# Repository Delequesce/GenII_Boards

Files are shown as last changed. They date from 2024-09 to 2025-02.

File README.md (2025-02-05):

## Rev 3 Changes

### Pi Interface and Power Board
1) ~~Set 4 LSBs of each color going into the RGB interface HIGH. This still allows for 4096 possible colors but frees up 12 total GPIOs.~~
2) ~~Replaced source switching circuitry with a source selector IC (LTC4412)~~. ~~Also implemented circuitry to enable the STM32 to shutdown and wakeup the Pi with the power button for better power management.~~ 
3) ~~Replaced the Pi Zero W with a Pi Zero 2 W.~~
4) ~~Added I2C RESET pin for enabling the capacitive touch screen~~
5) ~~Moved the FPC connector to the Measurement Board to the top of the board to ease assembly.~~ 
6) ~~Moved the RGB and I2C connectors to the screen closer to the edge (or top with flipped connections) to ease assembly.~~ 
7) ~~Fixed wiring issues for Vdd and Vcc out to the Measurement Board.~~
8) ~~Increased the size of the mounting holes for the battery cables to ease connection. (0.65 mm diameter for 22 AWG)~~
9) ~~Generally improved power routing~~
10) ~~Improved PWM backlight enable routing for better fidelity.~~
11) ~~Specced out smaller battery connectors to ease assembly and reduce size. (22 AWG, Amazon)~~
12) ~~Moved the Vdd Main LDO to the Measurement Board~~
13) ~~Added a fuse to the TPS2400 circuit and also a fuse after the source selector.~~
14) ~~Added a small board meant to be separated for interfacing the pushbutton reset switch with the rest of the circuit.~~

### Measurement Board
1) ~~Fixed PWM Heater signal routing~~ 
2) ~~Flipped FPC connector to Pi Board to top of board to ease assembly. Checked wiring against the Pi board.~~
3) ~~Moved Vdd Main LDO from Pi Board.~~ 
4) ~~Added external interrupt pin and Vcc controller output pin to interface with external pushbutton board. Needed to add 50 mils (1.27 mm) to board length.~~
5) ~~Changed the ADR4530 to the MAX6070, a cheaper buffered reference requiring fewer parts.~~

### Heater Board
1) ~~Reduced the size of vias and made more of them for better heating and lower losses. ~~
2) Moved the thermistors slightly farther from the center to improve temperature tracking. Alternately just reduced the size of the heating area to improve tracking without separating the thermistors from the chip. (Maybe)

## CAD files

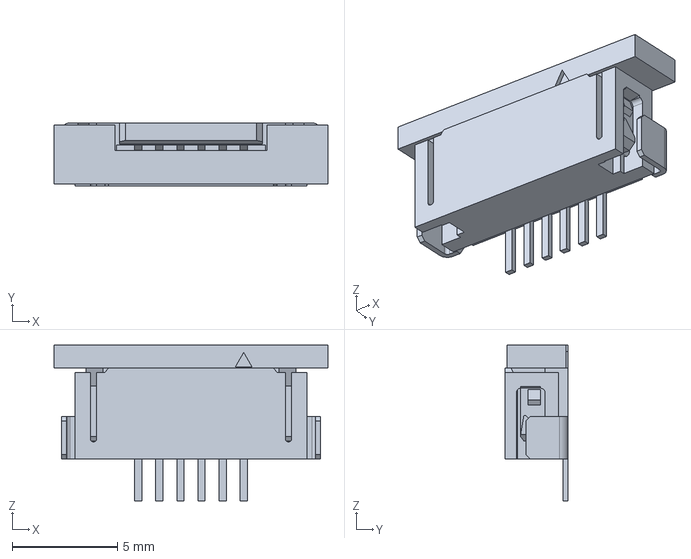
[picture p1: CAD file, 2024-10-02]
Raspi_Zero_TFT_Interface/Molex_0522710679/52271-0679.step
13.0 x 3.00 x 7.40 mm

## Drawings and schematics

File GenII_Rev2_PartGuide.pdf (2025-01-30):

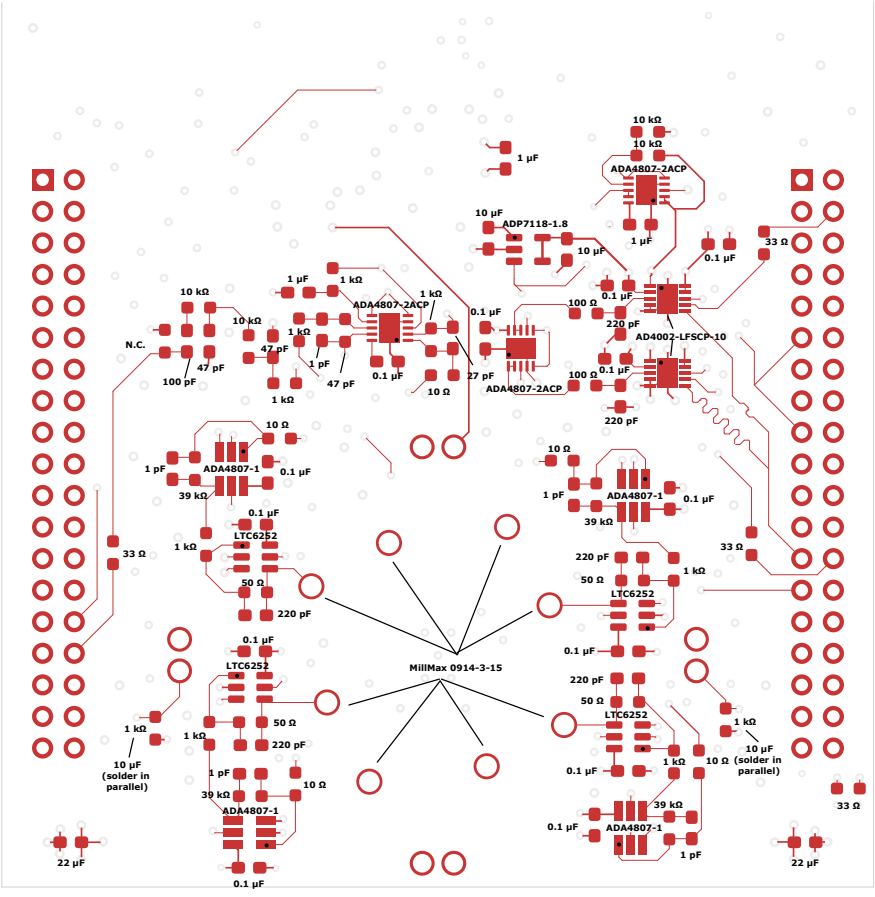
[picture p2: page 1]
10 μF (solder in parallel); ADA4807-2ACP; AD4002-LFSCP-10; ADA4807-1; LTC6252; MillMax 0914-3-15; ADP7118-1.8

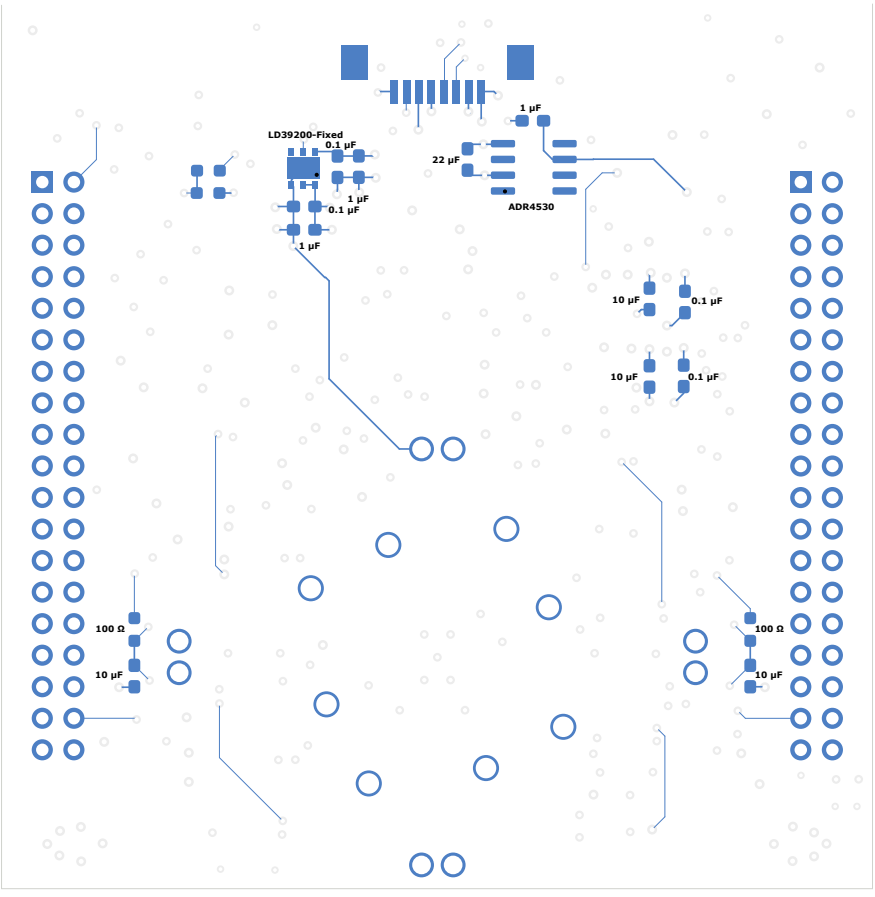
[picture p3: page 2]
LD39200-Fixed 0.1 μF; ADR4530

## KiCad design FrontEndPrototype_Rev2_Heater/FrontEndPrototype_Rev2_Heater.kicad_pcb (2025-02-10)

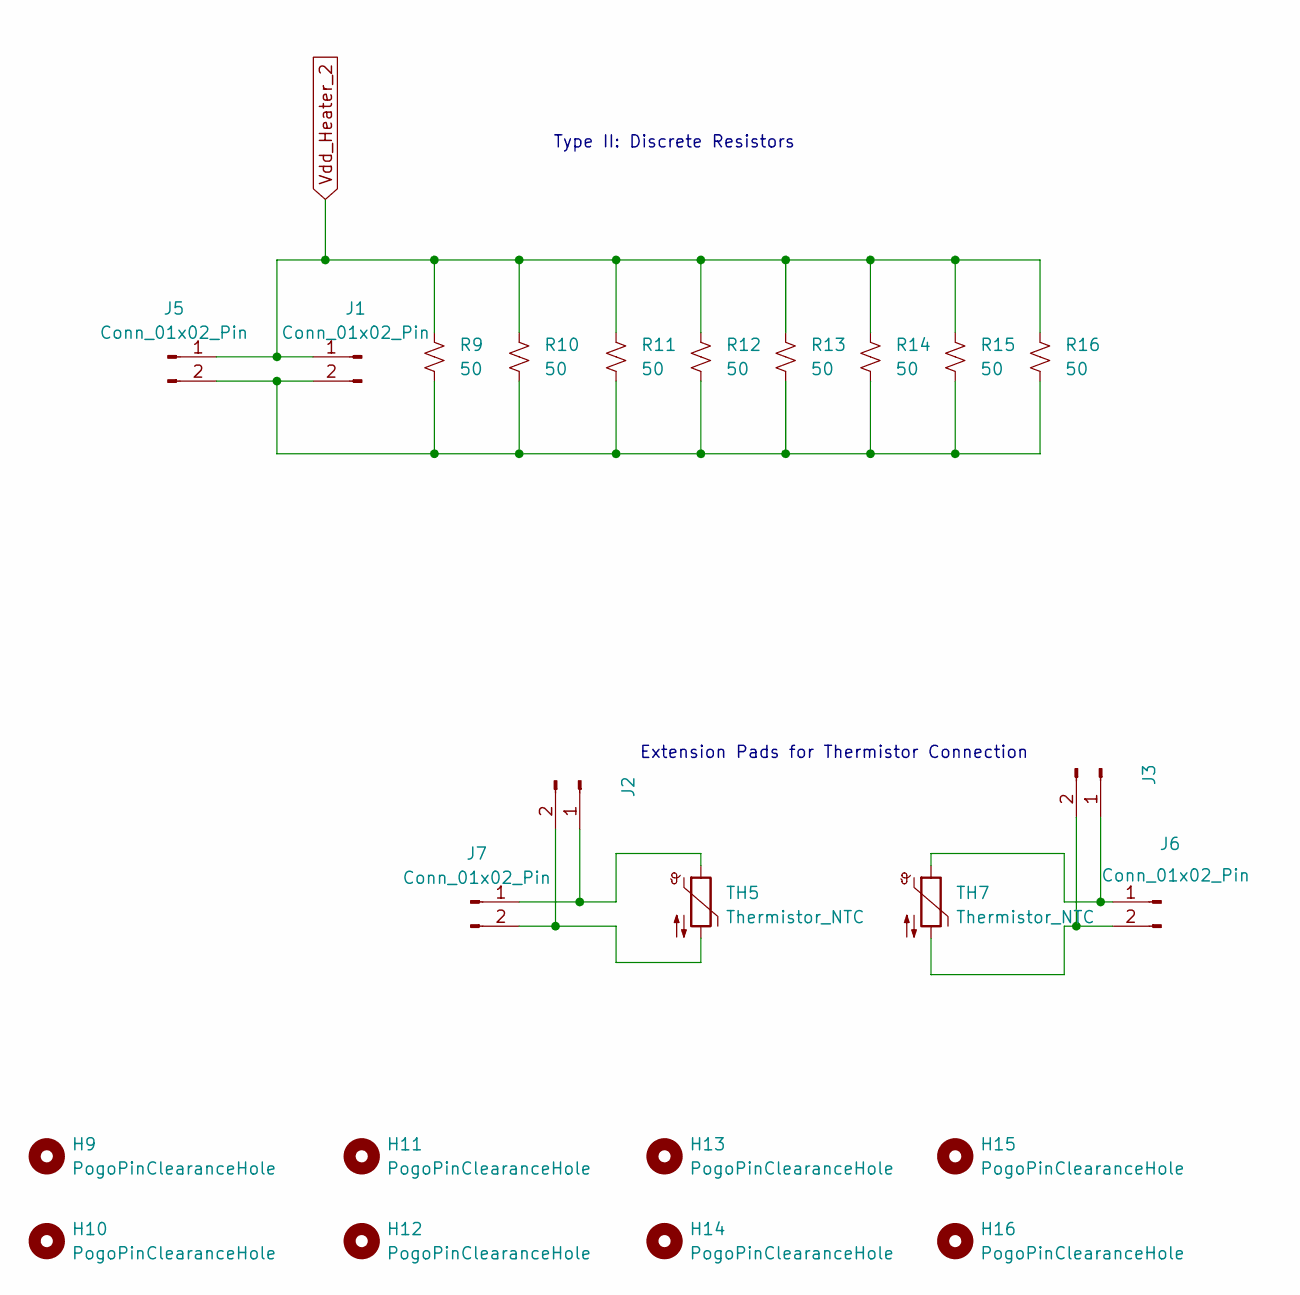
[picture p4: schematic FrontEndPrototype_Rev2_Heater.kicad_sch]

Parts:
H9, H10, H11, H12, H13, H14, H15, H16: PogoPinClearanceHole; PogoClearanceHole
J1, J5, J6, J7: Conn_01x02_Pin; Samtec_Pin_Socket_SS_102_G_2
J2, J3: Conn_01x02_Pin; Thermistor_ExtensionPad
R9, R10, R11, R12, R13, R14, R15, R16: 50; R_2010_5025Metric_Pad1.40x2.65mm_HandSolder
TH5, TH7: Thermistor_NTC; R_0603_1608Metric_Pad0.98x0.95mm_HandSolder

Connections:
unnamed: J1.2, J5.2, R9.1, R10.1, R11.1, R12.1, R13.1, R14.1, R15.1, R16.1
unnamed: J2.1, J7.1, TH5.1
unnamed: J2.2, J7.2, TH5.2
unnamed: J3.1, J6.1, TH7.1
unnamed: J3.2, J6.2, TH7.2
Vdd_Heater_2: J1.1, J5.1, R9.2, R10.2, R11.2, R12.2, R13.2, R14.2, R15.2, R16.2

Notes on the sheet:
Extension Pads for Thermistor Connection
Type II: Discrete Resistors

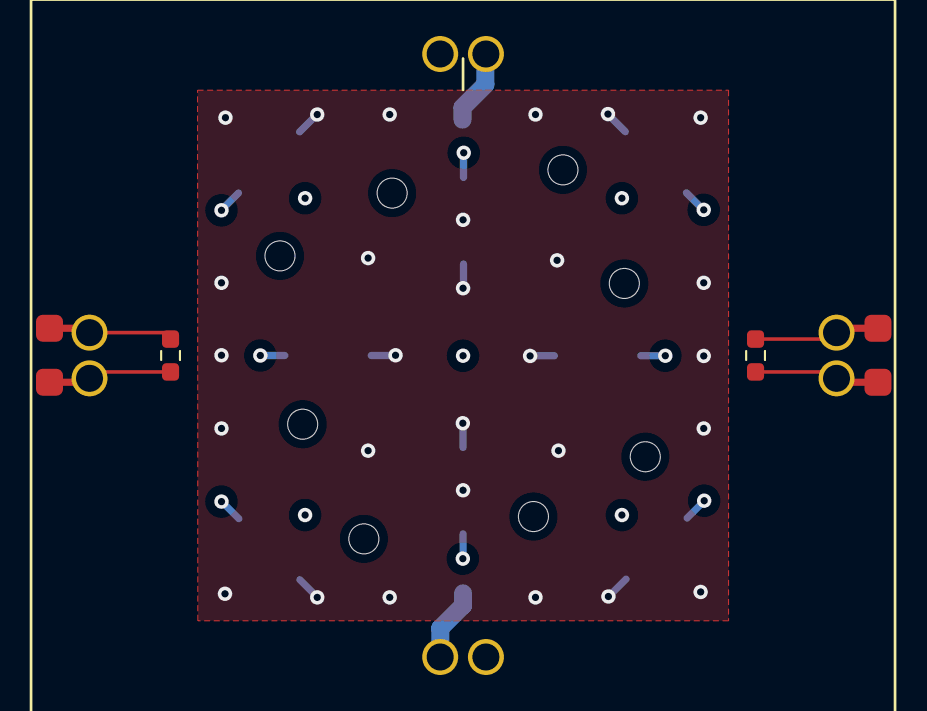
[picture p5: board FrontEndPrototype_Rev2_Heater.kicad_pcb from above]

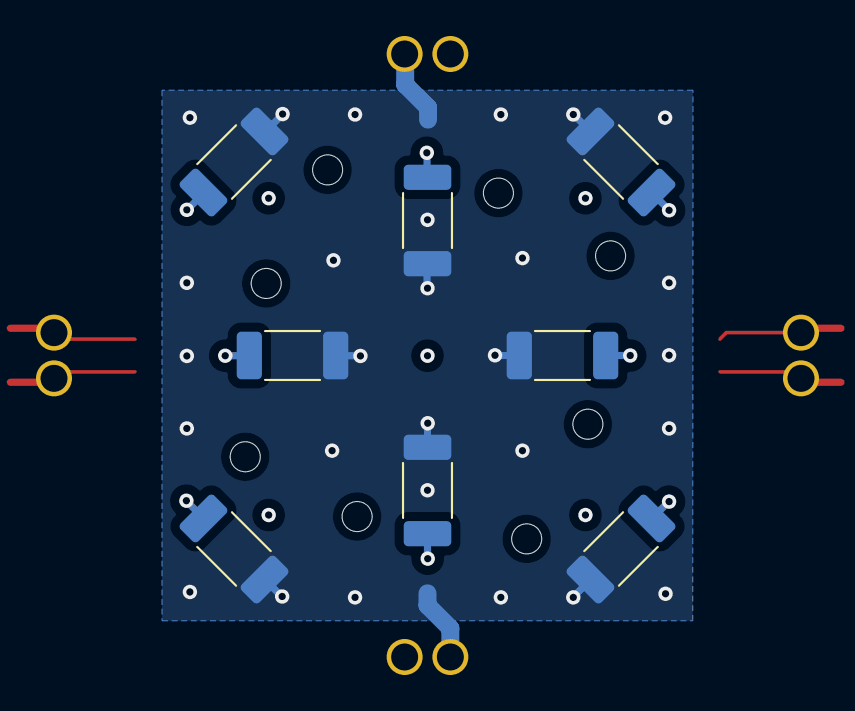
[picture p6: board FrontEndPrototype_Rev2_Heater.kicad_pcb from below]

Board: 4 copper layers, 24 parts (8 on the bottom side), 6 nets.

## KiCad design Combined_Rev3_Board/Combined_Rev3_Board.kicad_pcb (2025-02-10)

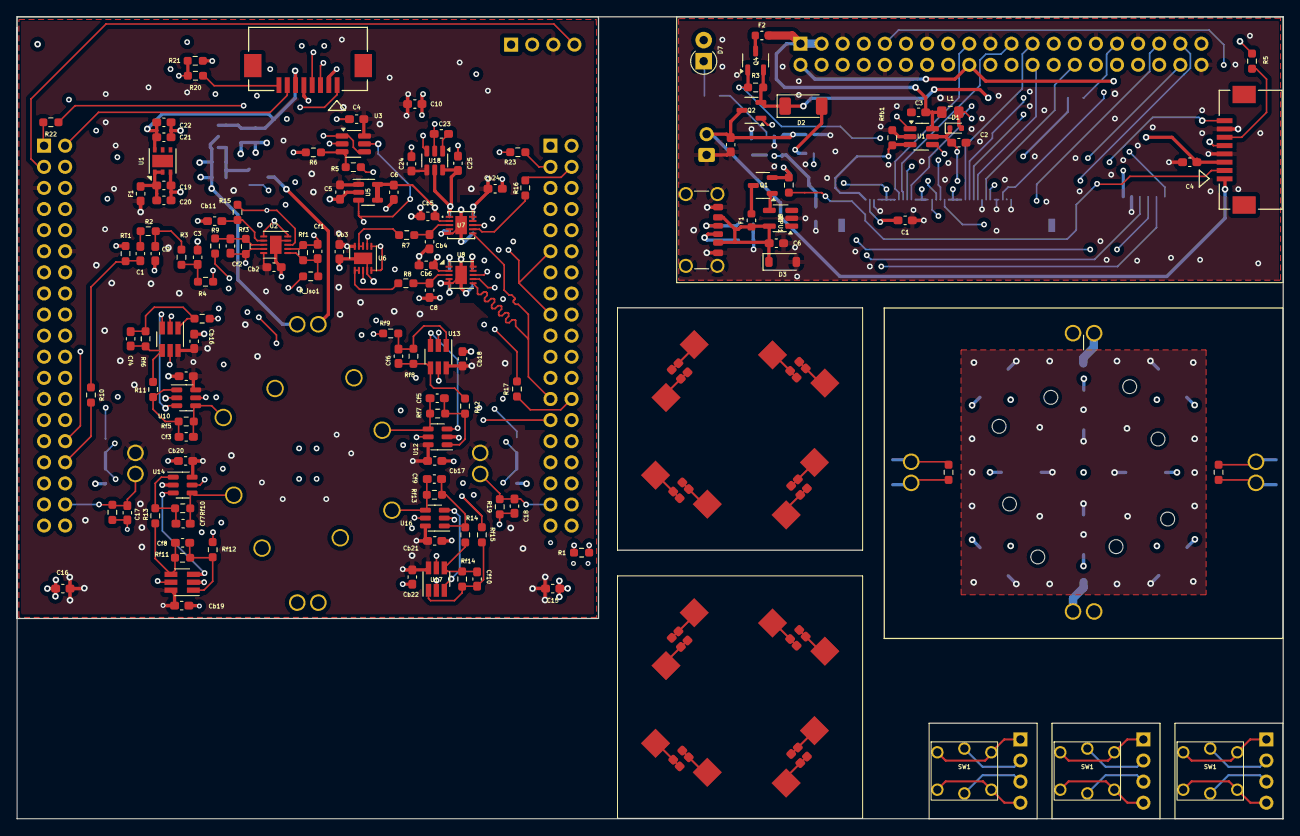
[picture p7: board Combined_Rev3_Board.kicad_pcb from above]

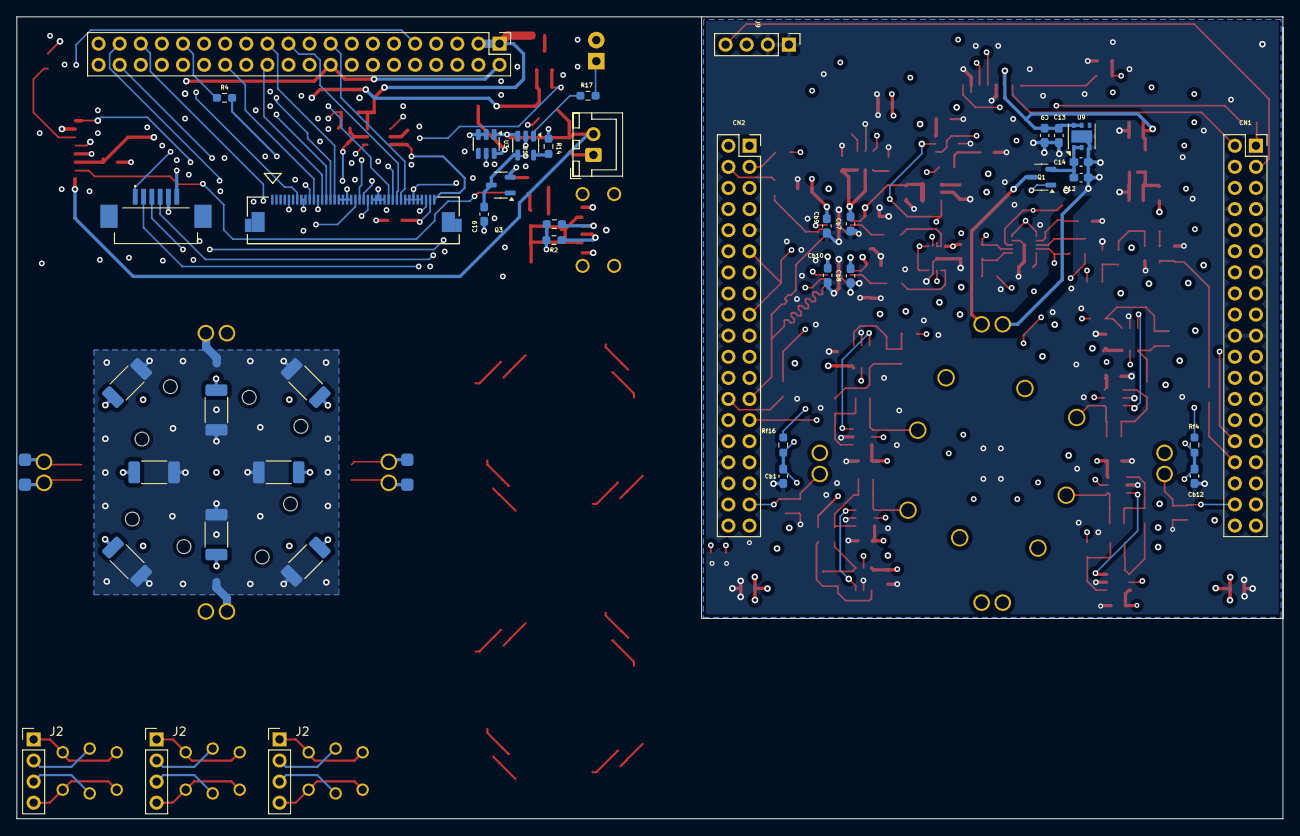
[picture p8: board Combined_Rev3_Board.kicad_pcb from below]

Board: 4 copper layers, 152.4 x 96.5 mm, 197 parts (43 on the bottom side), 122 nets.

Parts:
C1: 100p; C_0603_1608Metric_Pad1.08x0.95mm_HandSolder
C1#2, C2, C3#2, C25: 1uF; C_0603_1608Metric_Pad1.08x0.95mm_HandSolder
C2#2, C3: 47p; C_0603_1608Metric_Pad1.08x0.95mm_HandSolder
C4, C23, C24: 0.1uF; C_0603_1608Metric_Pad1.08x0.95mm_HandSolder
C4#2, C15, C16: 22u; C_0603_1608Metric_Pad1.08x0.95mm_HandSolder
C5, C6, C17, C18: 10uF; C_0603_1608Metric_Pad1.08x0.95mm_HandSolder
C6#2: 0.1u; C_0603_1608Metric_Pad1.08x0.95mm_HandSolder
C8: 220p; C_0603_1608Metric_Pad1.08x0.95mm_HandSolder
C9, C12, C20#2, C21: 1uF/XR5; C_0603_1608Metric_Pad1.08x0.95mm_HandSolder
C10: 22uF; C_0603_1608Metric_Pad1.08x0.95mm_HandSolder
C13, C14, C19, C22: 100n; C_0603_1608Metric_Pad1.08x0.95mm_HandSolder
C19#2, C20: 10u; C_0603_1608Metric_Pad1.08x0.95mm_HandSolder
CN1: USB_C_Receptacle_PowerOnly_6P; USB_C_Receptacle_GCT_USB4125-xx-x_6P_TopMnt_Horizontal
CN1#2, CN2: Conn_02x19_Odd_Even; PinSocket_2x19_P2.54mm_Vertical
CN2#2: B2B-XH-A; JST_XH_B2B-XH-A_1x02_P2.50mm_Vertical
CN3: 522070860; CON_522070860_MOL
CN3#2: Molex FPC 541044031; CON_541044031_MOL
CN4, CN5, CN6, CN7: Conn_01x02_Pin; Samtec_Pin_Socket_SS_102_G_2
CN4#2: Molex FPC 52271-0679; MOLEX_52271-0679
CN5#2: Conn_02x20_Odd_Even; PinHeader_2x20_P2.54mm_Vertical
Cb1, Cb7, Cb8, Cb12: 10u; C_0603_1608Metric_Pad1.08x0.95mm_HandSolder
Cb2, Cb3, Cb5, Cb6, Cb9, Cb10, Cb15, Cb16, Cb17, Cb18, Cb19, Cb20, Cb21, Cb22, Cb24: 0.1u; C_0603_1608Metric_Pad1.08x0.95mm_HandSolder
Cb4: 220p; C_0603_1608Metric_Pad1.08x0.95mm_HandSolder
Cb11: 1u; C_0603_1608Metric_Pad1.08x0.95mm_HandSolder
Cf1: 27p; C_0603_1608Metric_Pad1.08x0.95mm_HandSolder
Cf2, Cf4, Cf6, Cf8, Cf10: 1p; C_0603_1608Metric_Pad1.08x0.95mm_HandSolder
Cf3, Cf5, Cf7, Cf9: 200p; C_0603_1608Metric_Pad1.08x0.95mm_HandSolder
D1: D_Schottky; D_SOD-523
D2: PMEG3030EP,115; D_SOD-128
D3: NC; D_SOD-123
D7: LED; D_T-1_P2.54mm_Vertical_AnodeUp
F1: 250mA Fast-Blow; Fuse_0603_1608Metric_Pad1.05x0.95mm_HandSolder
F1#2, F2: 1.5 A Slow-Blow; Fuse_0603_1608Metric
H9, H10, H11, H12, H13, H14, H15, H16: PogoPinClearanceHole; PogoClearanceHole
J1: 522070860; CON_522070860_MOL
J1#2, J2, J3, J4, J5#2, J6#2, J7#2, J8: MIllMaxSpringConnector; MillMax_0914-2
J1#3, J5, J6, J7: Conn_01x02_Pin; Samtec_Pin_Socket_SS_102_G_2
J2#2, J3#2: Conn_01x02_Pin; Thermistor_ExtensionPad
J2#3, J2#4, J2#5: Conn_01x04_Pin; PinHeader_1x04_P2.54mm_Vertical
J9: Connector to Power Switch; PinHeader_1x04_P2.54mm_Vertical
L1: 22uH; L_0805_2012Metric_Pad1.15x1.40mm_HandSolder
Q1: DMG3406L-7; SOT-23-3
Q1#2, Q2, Q3, Q4: SSM3J358R; SOT-23-3
R1, R4#2, R5#2, R10, R16, R17, R22: 33; R_0603_1608Metric_Pad0.98x0.95mm_HandSolder
R1#2, R2#2: 5.1k; R_0603_1608Metric_Pad0.98x0.95mm_HandSolder
R2, R3, R3#2, R5, R6, R20, R21: 10k; R_0603_1608Metric_Pad0.98x0.95mm_HandSolder
R4, R9, R11, R12, R13, R14, R15, R17#2, R18, R19: 1k; R_0603_1608Metric_Pad0.98x0.95mm_HandSolder
R7, R8: 100; R_0603_1608Metric_Pad0.98x0.95mm_HandSolder
R9#2, R10#2, R11#2, R12#2, R13#2, R14#3, R15#2, R16#2: 50; R_2010_5025Metric_Pad1.40x2.65mm_HandSolder
R14#2: 2k; R_0603_1608Metric_Pad0.98x0.95mm_HandSolder
R23: 27k; R_0603_1608Metric_Pad0.98x0.95mm_HandSolder
RPU1: 10k; R_0603_1608Metric_Pad0.98x0.95mm_HandSolder
RT1: NC; R_0603_1608Metric_Pad0.98x0.95mm_HandSolder
R_iso1: 10; R_0603_1608Metric_Pad0.98x0.95mm_HandSolder
Rf1: 1.5k; R_0603_1608Metric_Pad0.98x0.95mm_HandSolder
Rf3, Rf6, Rf8, Rf11, Rf14: 39k; R_0603_1608Metric_Pad0.98x0.95mm_HandSolder
Rf4, Rf16: 100; R_0603_1608Metric_Pad0.98x0.95mm_HandSolder
Rf5, Rf7, Rf10, Rf13: 50; R_0603_1608Metric_Pad0.98x0.95mm_HandSolder
Rf9, Rf12, Rf15: 10; R_0603_1608Metric_Pad0.98x0.95mm_HandSolder
Rfb1: 13; R_0603_1608Metric_Pad0.98x0.95mm_HandSolder
Riso1: 10; R_0603_1608Metric_Pad0.98x0.95mm_HandSolder
SW1, SW1#2, SW1#3: Off-mom push button; TL1240_LED_Switch
TH5, TH7: Thermistor_NTC; R_0603_1608Metric_Pad0.98x0.95mm_HandSolder
U1, U9: LD39200_Fixed; DFN-6-1EP_3x3mm_P0.95mm_EP1.7x2.6mm
U1#2: AP5725WG-7; SOT-23-6_Handsoldering
U2, U6: ADA4807-2ACP; LFCSP-WD-10-1EP_3x3mm_P0.5mm_EP1.64x2.38mm
U3, U11, U13, U15, U17: ADA4807-1; SOT-23-6_Handsoldering
U3#2: LTC4412xS6; TSOT-23-6
U5: ADP7118-1.8; TSOT-23-5
U7: AD4002_LFSCP-10; CP_10_9_ADI
U8: TPS2400; SOT-23-5_HandSoldering
U8#2: AD4002_LFSCP-10; LFCSP-WD-10-1EP_3x3mm_P0.5mm_EP1.64x2.38mm
U10, U12, U14, U16: LTC6252; TSOT-23-6
U11#2: MCP73831-2-OT; SOT-23-5
U18: MAX6070BAUT30+T; SOT-23-6

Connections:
/3V3_Pi: CN3#2.17, CN3#2.18, CN3#2.19, CN3#2.20, CN3#2.25, CN3#2.26, CN3#2.27, CN3#2.28, CN3#2.33, CN3#2.34, CN3#2.35, CN3#2.36, CN3#2.37, CN4#2.6, CN5#2.2, CN5#2.18
/ABBCore_Alt/TIA_1/V_MID: Cb12.2, Rf4.2, U10.3 (+), U11.3 (+), U14.3 (+), U15.3 (+)
/ABBCore_Alt/TIA_2/V_MID: Cb1.2, Rf16.2, U12.3 (+), U13.3 (+), U16.3 (+), U17.3 (+)
/ABBCore_Alt/V_Drive: J3.1, J4.1, J7#2.1, J8.1, R9.2, R_iso1.2
/ABBCore_Alt/V_Exc: Cf2.2, Rf3.2, U2.9, U6.7 (+)
/ABBCore_Alt/V_Resp: Rf9.2, Rf12.2, Rf15.2, Riso1.2, U6.3 (+)
/B4: CN3#2.16, CN5#2.23
/B5: CN3#2.15, CN5#2.22
/B6: CN3#2.14, CN5#2.20
/B7: CN3#2.13, CN5#2.24
/CLK: CN3#2.11, CN5#2.28
/DE: CN3#2.7, CN5#2.27
/DISP: CN3#2.10, CN5#2.37
/G4: CN3#2.24, CN5#2.35
/G5: CN3#2.23, CN5#2.12
/G6: CN3#2.22, CN5#2.11
/G7: CN3#2.21, CN5#2.36
/Heater_Interface/Heater+: CN7.2, Q1#2.3 (D)
/LED+: C1#2.2, C2.1, CN3#2.39, D1.1 (K), U1#2.5 (OVP)
/LED-: CN3#2.40, Rfb1.2, U1#2.3 (FB)
/MCU Connections/PA1: CN1#2.32, R10.1
/MCU Connections/PB4: CN2.4, R16.2
/MCU Connections/PB6: CN2.34, R1.1
/MCU Connections/PB8: CN2.3, R23.1
/MCU Connections/PB11: CN1#2.1, R22.2
/MCU Connections/PB15: CN2.26, R17.1
/MCU Connections/PC1: CN1#2.30, R20.2, R21.1
/PWM_EN: R4#2.1, U1#2.4 (EN)
/Power_Management_Minimal/InputVoltageProtection/Vout: D2.2 (A), Q1.2 (S), Q3.2 (S), RPU1.1, U3#2.6 (SENSE)
/Power_Management_Minimal/VBus: C6#2.1, CN1.A9 (VBUS), CN1.B9 (VBUS), D3.1 (K), F1#2.1, U8.5 (Vin)
/R4: CN3#2.32, CN5#2.17
/R5: CN3#2.31, CN5#2.21
/R6: CN3#2.30, CN5#2.38
/R7: CN3#2.29, CN5#2.14
/SCL: CN4#2.4, CN5#2.6
/SDA: CN4#2.3, CN5#2.4
/UART_RX: CN5#2.9, J1.5
/UART_TX: J1.6, R5#2.1
/USB_VCC1: CN1.A5 (CC1), R1#2.2
/USB_VCC2: CN1.B5 (CC2), R2#2.2
/V_Batt: C20.1, CN2#2.2, J1.1, Q2.3 (D), U3#2.1 (VIN), U11#2.3 (V_{BAT})
/Vcc_MeasBoard: C4#2.1, D2.1 (K), J1.3, Q2.2 (S), Q4.2 (S), R3.2
/Vcc_Pi_Screen: C3#2.1, CN5#2.1, CN5#2.3, F2.1, L1.1, U1#2.6 (VIN)
/~CHARGE_EN: J1.2, Q3.1 (G), RPU1.2
/~INT: CN4#2.2, CN5#2.8
/~PWR_EN: J1.8, Q4.1 (G), R3.1
/~RESET: CN4#2.1, CN5#2.16
ADC_VREF: C25.2, Cb7.2, Cb8.2, R5.1, U7.1 (REF), U8#2.1 (REF), U18.5 (OUTS), U18.6 (OUTF)
CCOut_1: Cf3.1, J6#2.1, Rf5.1, U10.4 (-)
CCOut_2: Cf5.1, J5#2.1, Rf7.1, U12.4 (-)
CCOut_3: Cf7.1, J2.1, Rf10.1, U14.4 (-)
CCOut_4: Cf9.1, J1#2.1, Rf13.1, U16.4 (-)
CNV: CN2.25, U7.6 (CNV), U8#2.6 (CNV)
DataOut1: R17.2, U8#2.7 (SDO)
Dataout0: R16.1, U7.7 (SDO)
GND: C1#2.1, C2.2, C2#2.2, C3.2, C3#2.2, C4.1, C4#2.2, C5.2, C6.2, C6#2.2, C8.1, C9.1, C10.1, C12.2, C13.2, C14.2, C15.1, C16.1, C17.2, C18.1, C19.2, C19#2.1, C20.2, C20#2.2, C21.1, C22.2, C23.1, C24.1, C25.1, CN1.A12 (GND), CN1.B12 (GND), CN1.S1 (SHIELD), CN1#2.8, CN1#2.19, CN1#2.20, CN2.9, CN2.20, CN2.32, CN2#2.1, CN3.2, CN3.5, CN3#2.5, CN3#2.8, CN3#2.9, CN3#2.12, CN3#2.38, CN4#2.5, CN5#2.5, CN5#2.10, CN5#2.13, CN5#2.19, CN5#2.26, CN5#2.29, CN5#2.33, CN5#2.40, CN7.1, Cb1.1, Cb2.1, Cb3.2, Cb4.1, Cb5.2, Cb6.2, Cb7.1, Cb8.1, Cb9.1, Cb10.1, Cb11.1, Cb12.1, Cb15.1, Cb16.1, Cb17.1, Cb18.1, Cb19.1, Cb20.1, Cb21.1, Cb22.1, Cb24.1, D3.2 (A), J1.4, J1.7, J9.1, J9.2, R1#2.1, R2#2.1, R6.2, R14#2.1, R18.1, R19.1, R21.2, RT1.1, Rfb1.1, U1.3 (GND), U1.7, U1#2.2 (GND), U2.4 (V-), U2.11 (EPAD), U3.2 (V-), U3#2.2 (GND), U3#2.3 (CTL), U5.2 (GND), U6.4 (V-), U6.11 (EPAD), U7.4 (IN-), U7.5 (GND), U7.11 (Pad), U8.2 (GND), U8#2.4 (IN-), U8#2.5 (GND), U8#2.11 (Pad), U9.3 (GND), U9.7, U10.2 (V-), U11.2 (V-), U11#2.2 (V_{SS}), U12.2 (V-), U13.2 (V-), U14.2 (V-), U15.2 (V-), U16.2 (V-), U17.2 (V-), U18.2 (GND)
Heater_PWM: Q1#2.1 (G), R23.2
MCU_SCK: CN2.11, CN2.17, U7.8 (SCK), U8#2.8 (SCK)
unnamed: C1.1, R2.1
unnamed: C2#2.1, R2.2, R3#2.1
unnamed: C3.1, R3#2.2, R4.1
unnamed: CN5#2.7, R5#2.2
unnamed: CN5#2.31, R4#2.2
unnamed: Cf1.1, R_iso1.1, Rf1.1, U2.1
unnamed: Cf3.2, R11.2, Rf5.2, U10.1
unnamed: Cf4.2, Rf6.2, Riso1.1, U11.1
unnamed: Cf5.2, R12.2, Rf7.2, U12.1
unnamed: Cf6.2, Rf8.2, Rf9.1, U13.1
unnamed: Cf7.2, R13.2, Rf10.2, U14.1
unnamed: Cf8.2, Rf11.2, Rf12.1, U15.1
unnamed: Cf9.2, R14.2, Rf13.2, U16.1
unnamed: Cf10.2, Rf14.2, Rf15.1, U17.1
unnamed: D1.2 (A), L1.2, U1#2.1 (SW)
unnamed: C19#2.2, D7.2 (A), Q3.3 (D), U11#2.4 (V_{DD})
unnamed: D7.1 (K), R17#2.2
unnamed: J1#3.2, J5.2, R9#2.1, R10#2.1, R11#2.1, R12#2.1, R13#2.1, R14#3.1, R15#2.1, R16#2.1
unnamed: J2#2.1, J2#3.1, J2#4.1, J2#5.1, J7.1, SW1.2, SW1#2.2, SW1#3.2, TH5.1
unnamed: J2#2.2, J2#3.2, J2#4.2, J2#5.2, J7.2, SW1.4 (A), SW1#2.4 (A), SW1#3.4 (A), TH5.2
unnamed: J2#3.3, J2#4.3, J2#5.3, SW1.3 (K), SW1#2.3 (K), SW1#3.3 (K)
unnamed: J2#3.4, J2#4.4, J2#5.4, SW1.1, SW1#2.1, SW1#3.1
unnamed: J3#2.1, J6.1, TH7.1
unnamed: J3#2.2, J6.2, TH7.2
unnamed: F1#2.2, Q1.3 (D)
unnamed: Q1.1 (G), U8.4 (Gate)
unnamed: C12.1, C14.1, Q1#2.2 (S), U9.1 (Vout), U9.2 (ADJ/SENSE)
unnamed: Q2.1 (G), U3#2.5 (GATE)
unnamed: F2.2, Q4.3 (D)
unnamed: C19.1, C20#2.1, F1.2, U1.1 (Vout), U1.2 (ADJ/SENSE)
unnamed: Cf1.2, R4.2, Rf1.2, U2.2 (-)
unnamed: Cb11.2, R15.2, U2.7 (+)
unnamed: Cf2.1, R9.1, Rf3.1, U2.8 (-)
unnamed: R5.2, R6.1, U3.3 (+)
unnamed: R8.2, U6.1, U6.2 (-)
unnamed: R7.2, U6.8 (-), U6.9
unnamed: Cb4.2, R7.1, U7.3 (IN+)
unnamed: C8.2, R8.1, U8#2.3 (IN+)
unnamed: Cf4.1, R11.1, Rf6.1, U11.4 (-)
unnamed: R14#2.2, U11#2.5 (PROG)
unnamed: R17#2.1, U11#2.1 (STAT)
unnamed: Cf6.1, R12.1, Rf8.1, U13.4 (-)
unnamed: Cf8.1, R13.1, Rf11.1, U15.4 (-)
unnamed: Cf10.1, R14.1, Rf14.1, U17.4 (-)
unnamed: C23.2, U18.1 (FILTER)
UART_RX: CN2.6, CN3.3
UART_TX: CN3.4, R1.2
V_Batt: CN3.8, R20.1
V_MID: R15.1, Rf4.1, Rf16.1, U2.3 (+), U3.1, U3.4 (-)
V_SIG: C1.2, R10.2, RT1.2
Vcc: C9.2, C13.1, C21.2, C22.1, CN3.6, U1.5 (EN), U1.6 (Vin), U9.5 (EN), U9.6 (Vin)
Vdd_ADC: C6.1, Cb5.1, Cb6.1, U5.4 (SENSE/ADJ), U5.5 (VOUT), U7.2 (Vdd), U8#2.2 (Vdd)
Vdd_Heater_2: J1#3.1, J5.1, R9#2.2, R10#2.2, R11#2.2, R12#2.2, R13#2.2, R14#3.2, R15#2.2, R16#2.2
Vdd_Main: C4.2, C5.1, C10.2, C15.2, C16.2, C24.2, CN1#2.5, CN1#2.12, CN4.1, CN5.1, Cb2.2, Cb3.1, Cb9.2, Cb10.2, Cb15.2, Cb16.2, Cb17.2, Cb18.2, Cb19.2, Cb20.2, Cb21.2, Cb22.2, Cb24.2, F1.1, J9.3, U2.10 (V+), U3.6 (V+), U5.1 (VIN), U6.10 (V+), U7.9 (SDI), U7.10 (VIO), U8#2.9 (SDI), U8#2.10 (VIO), U10.6 (V+), U11.6 (V+), U12.6 (V+), U13.6 (V+), U14.6 (V+), U15.6 (V+), U16.6 (V+), U17.6 (V+), U18.4 (VIN)
Vth_1: C17.1, CN1#2.36, CN4.2, R18.2
Vth_2: C18.2, CN2.35, CN5.2, R19.2
~ADC1_SHDN: CN2.1, U2.5 (~DISABLE1), U2.6 (~DISABLE2), U3.5 (~DISABLE), U5.3 (EN), U6.5 (~DISABLE1), U6.6 (~DISABLE2), U18.3 (EN)
~CHARGE_EN: CN1#2.2, CN3.7
~PWR_EN: CN3.1, R22.1
~Power_Switch_INT: CN1#2.3, J9.4
~TIA1_SHDN: CN1#2.28, U10.5 (~SHDN), U11.5 (~DISABLE)
~TIA2_SHDN: CN2.27, U12.5 (~SHDN), U13.5 (~DISABLE)
~TIA3_SHDN: CN1#2.34, U14.5 (~SHDN), U15.5 (~DISABLE)
~TIA4_SHDN: CN2.33, U16.5 (~SHDN), U17.5 (~DISABLE)

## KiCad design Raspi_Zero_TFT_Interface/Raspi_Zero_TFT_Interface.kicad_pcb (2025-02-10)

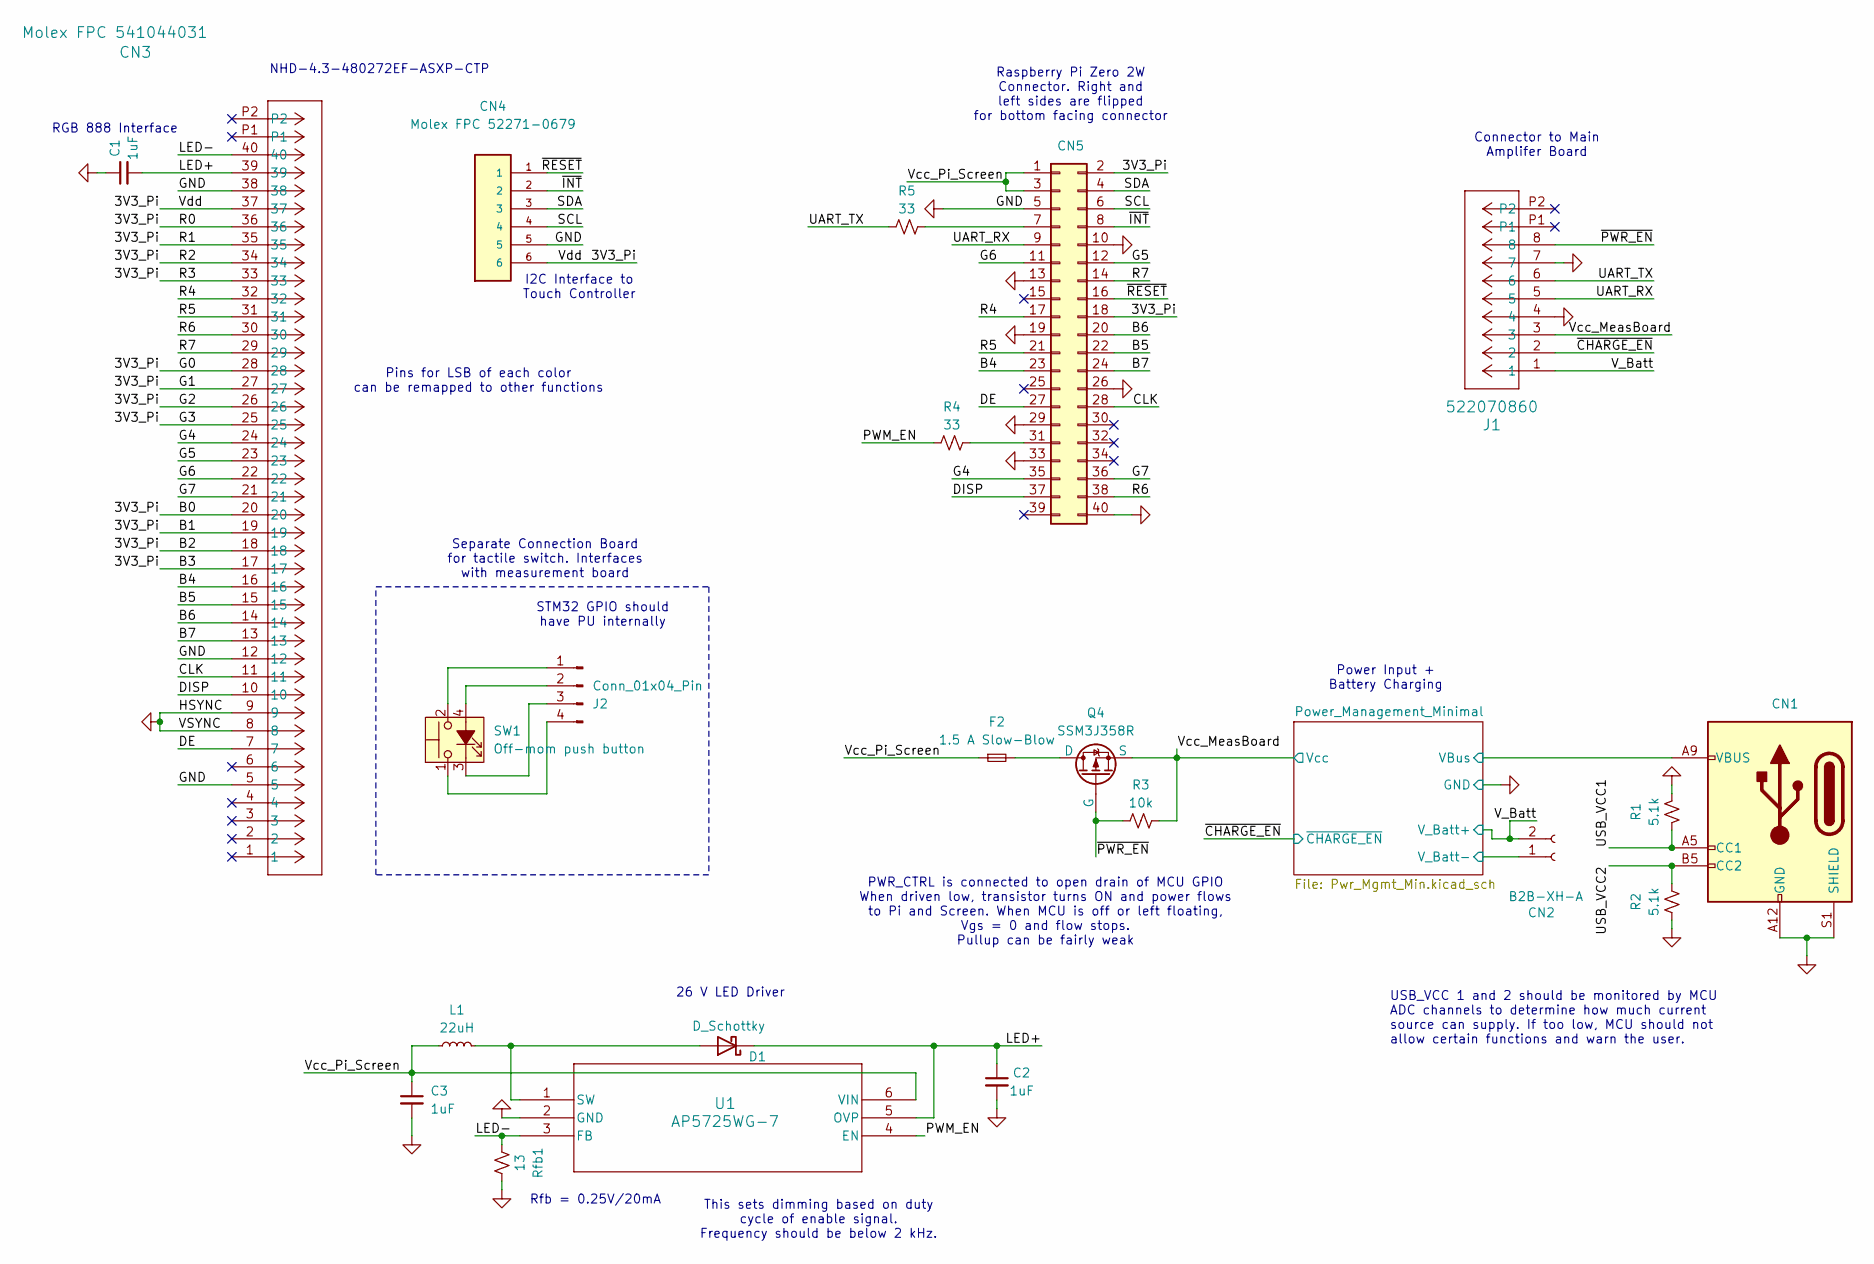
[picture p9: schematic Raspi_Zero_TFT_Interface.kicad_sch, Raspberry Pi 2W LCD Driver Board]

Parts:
C1, C2, C3: 1uF; C_0603_1608Metric_Pad1.08x0.95mm_HandSolder
CN1: USB_C_Receptacle_PowerOnly_6P; USB_C_Receptacle_GCT_USB4125-xx-x_6P_TopMnt_Horizontal
CN2: B2B-XH-A; JST_XH_B2B-XH-A_1x02_P2.50mm_Vertical
CN3: Molex FPC 541044031; CON_541044031_MOL
CN4: Molex FPC 52271-0679; MOLEX_52271-0679
CN5: Conn_02x20_Odd_Even; PinHeader_2x20_P2.54mm_Vertical
D1: D_Schottky; D_SOD-523
F2: 1.5 A Slow-Blow; Fuse_0603_1608Metric
J1: 522070860; CON_522070860_MOL
J2: Conn_01x04_Pin; PinHeader_1x04_P2.54mm_Vertical
L1: 22uH; L_0805_2012Metric_Pad1.15x1.40mm_HandSolder
Q4: SSM3J358R; SOT-23-3
R1, R2: 5.1k; R_0603_1608Metric_Pad0.98x0.95mm_HandSolder
R3: 10k; R_0603_1608Metric_Pad0.98x0.95mm_HandSolder
R4, R5: 33; R_0603_1608Metric_Pad0.98x0.95mm_HandSolder
Rfb1: 13; R_0603_1608Metric_Pad0.98x0.95mm_HandSolder
SW1: Off-mom push button; TL1240_LED_Switch
U1: AP5725WG-7; SOT-23-6_Handsoldering

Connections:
/3V3_Pi: CN3.17, CN3.18, CN3.19, CN3.20, CN3.25, CN3.26, CN3.27, CN3.28, CN3.33, CN3.34, CN3.35, CN3.36, CN3.37, CN4.6, CN5.2, CN5.18
/B4: CN3.16, CN5.23
/B5: CN3.15, CN5.22
/B6: CN3.14, CN5.20
/B7: CN3.13, CN5.24
/CLK: CN3.11, CN5.28
/DE: CN3.7, CN5.27
/DISP: CN3.10, CN5.37
/G4: CN3.24, CN5.35
/G5: CN3.23, CN5.12
/G6: CN3.22, CN5.11
/G7: CN3.21, CN5.36
/LED+: C1.2, C2.1, CN3.39, D1.1 (K), U1.5 (OVP)
/LED-: CN3.40, Rfb1.2, U1.3 (FB)
/PWM_EN: R4.1, U1.4 (EN)
/Power_Management_Minimal/VBus: CN1.A9 (VBUS), CN1.B9 (VBUS); also elsewhere on the board
/R4: CN3.32, CN5.17
/R5: CN3.31, CN5.21
/R6: CN3.30, CN5.38
/R7: CN3.29, CN5.14
/SCL: CN4.4, CN5.6
/SDA: CN4.3, CN5.4
/UART_RX: CN5.9, J1.5
/UART_TX: J1.6, R5.1
/USB_VCC1: CN1.A5 (CC1), R1.2
/USB_VCC2: CN1.B5 (CC2), R2.2
/V_Batt: CN2.2, J1.1; also elsewhere on the board
/Vcc_MeasBoard: J1.3, Q4.2 (S), R3.2; also elsewhere on the board
/Vcc_Pi_Screen: C3.1, CN5.1, CN5.3, F2.1, L1.1, U1.6 (VIN)
/~CHARGE_EN: J1.2; also elsewhere on the board
/~INT: CN4.2, CN5.8
/~PWR_EN: J1.8, Q4.1 (G), R3.1
/~RESET: CN4.1, CN5.16
GND: C1.1, C2.2, C3.2, CN1.A12 (GND), CN1.B12 (GND), CN1.S1 (SHIELD), CN2.1, CN3.5, CN3.8, CN3.9, CN3.12, CN3.38, CN4.5, CN5.5, CN5.10, CN5.13, CN5.19, CN5.26, CN5.29, CN5.33, CN5.40, J1.4, J1.7, R1.1, R2.1, Rfb1.1, U1.2 (GND); also elsewhere on the board
unnamed: CN5.7, R5.2
unnamed: CN5.31, R4.2
unnamed: D1.2 (A), L1.2, U1.1 (SW)
unnamed: J2.1, SW1.2
unnamed: J2.2, SW1.4 (A)
unnamed: J2.3, SW1.3 (K)
unnamed: J2.4, SW1.1
unnamed: F2.2, Q4.3 (D)

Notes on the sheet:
I2C Interface to Touch Controller
RGB 888 Interface
STM32 GPIO should have PU internally
Pins for LSB of each color can be remapped to other functions
NHD-4.3-480272EF-ASXP-CTP
USB_VCC 1 and 2 should be monitored by MCU ADC channels to determine how much current source can supply. If too low, MCU should not allow certain functions and warn the user.
Separate Connection Board for tactile switch. Interfaces with measurement board
Raspberry Pi Zero 2W Connector. Right and left sides are flipped for bottom facing connector
PWR_CTRL is connected to open drain of MCU GPIO When driven low, transistor turns ON and power flows to Pi and Screen. When MCU is off or left floating, Vgs = 0 and flow stops. Pullup can be fairly weak
This sets dimming based on duty cycle of enable signal. Frequency should be below 2 kHz.
26 V LED Driver
Connector to Main Amplifer Board
Rfb = 0.25V/20mA
Power Input + Battery Charging

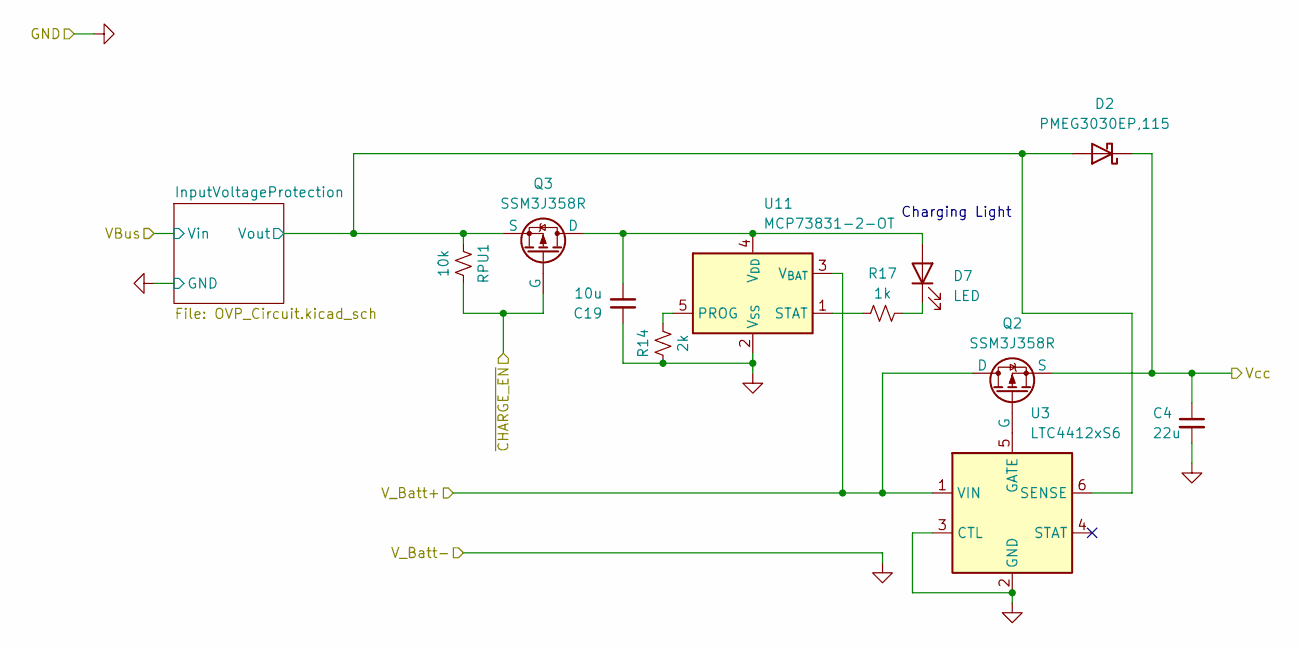
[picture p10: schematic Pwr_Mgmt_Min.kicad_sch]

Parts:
C4: 22u; C_0603_1608Metric_Pad1.08x0.95mm_HandSolder
C19: 10u; C_0603_1608Metric_Pad1.08x0.95mm_HandSolder
D2: PMEG3030EP,115; D_SOD-128
D7: LED; D_T-1_P2.54mm_Vertical_AnodeUp
Q2, Q3: SSM3J358R; SOT-23-3
R14: 2k; R_0603_1608Metric_Pad0.98x0.95mm_HandSolder
R17: 1k; R_0603_1608Metric_Pad0.98x0.95mm_HandSolder
RPU1: 10k; R_0603_1608Metric_Pad0.98x0.95mm_HandSolder
U3: LTC4412xS6; TSOT-23-6
U11: MCP73831-2-OT; SOT-23-5

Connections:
/Power_Management_Minimal/InputVoltageProtection/Vout: D2.2 (A), Q3.2 (S), RPU1.1, U3.6 (SENSE); also elsewhere on the board
/V_Batt: Q2.3 (D), U3.1 (VIN), U11.3 (V_{BAT}); also elsewhere on the board
/Vcc_MeasBoard: C4.1, D2.1 (K), Q2.2 (S); also elsewhere on the board
/~CHARGE_EN: Q3.1 (G), RPU1.2; also elsewhere on the board
GND: C4.2, C19.1, R14.1, U3.2 (GND), U3.3 (CTL), U11.2 (V_{SS}); also elsewhere on the board
unnamed: C19.2, D7.2 (A), Q3.3 (D), U11.4 (V_{DD})
unnamed: D7.1 (K), R17.2
unnamed: Q2.1 (G), U3.5 (GATE)
unnamed: R14.2, U11.5 (PROG)
unnamed: R17.1, U11.1 (STAT)

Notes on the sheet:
Charging Light

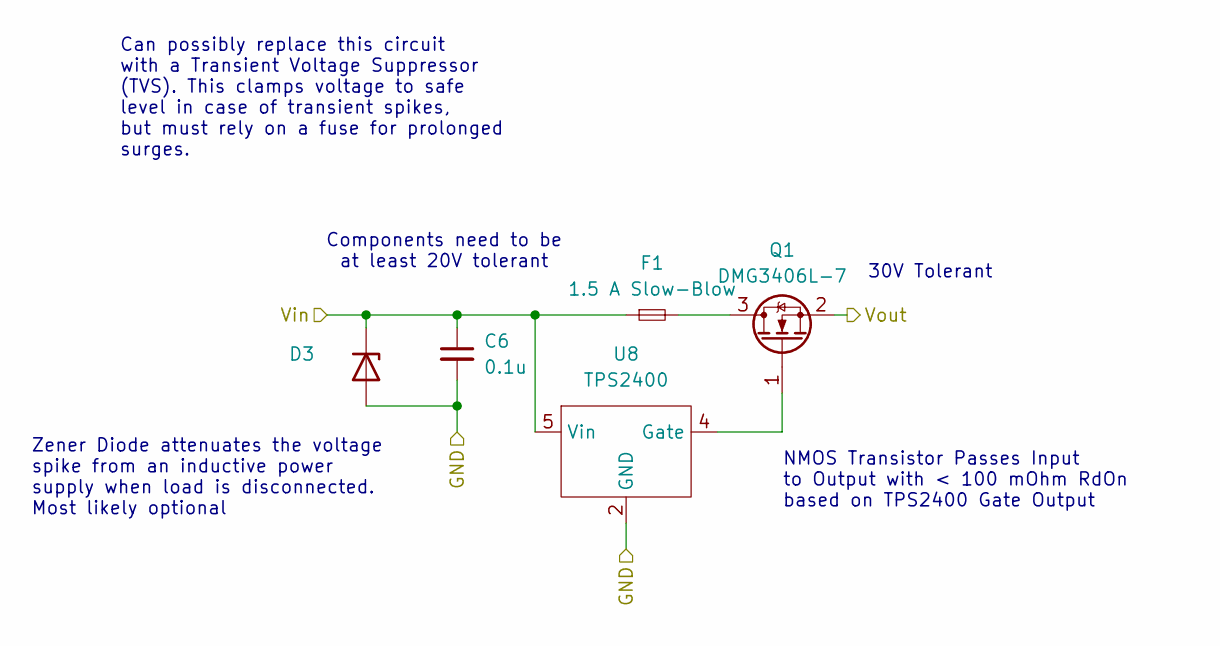
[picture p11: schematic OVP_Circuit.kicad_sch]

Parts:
C6: 0.1u; C_0603_1608Metric_Pad1.08x0.95mm_HandSolder
D3: NC; D_SOD-123
F1: 1.5 A Slow-Blow; Fuse_0603_1608Metric
Q1: DMG3406L-7; SOT-23-3
U8: TPS2400; SOT-23-5_HandSoldering

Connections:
/Power_Management_Minimal/InputVoltageProtection/Vout: Q1.2 (S); also elsewhere on the board
/Power_Management_Minimal/VBus: C6.1, D3.1 (K), F1.1, U8.5 (Vin); also elsewhere on the board
GND: C6.2, D3.2 (A), U8.2 (GND); also elsewhere on the board
unnamed: F1.2, Q1.3 (D)
unnamed: Q1.1 (G), U8.4 (Gate)

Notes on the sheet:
30V Tolerant
NMOS Transistor Passes Input to Output with < 100 mOhm RdOn based on TPS2400 Gate Output
Components need to be at least 20V tolerant
Zener Diode attenuates the voltage spike from an inductive power supply when load is disconnected. Most likely optional
Can possibly replace this circuit with a Transient Voltage Suppressor (TVS). This clamps voltage to safe level in case of transient spikes, but must rely on a fuse for prolonged surges.

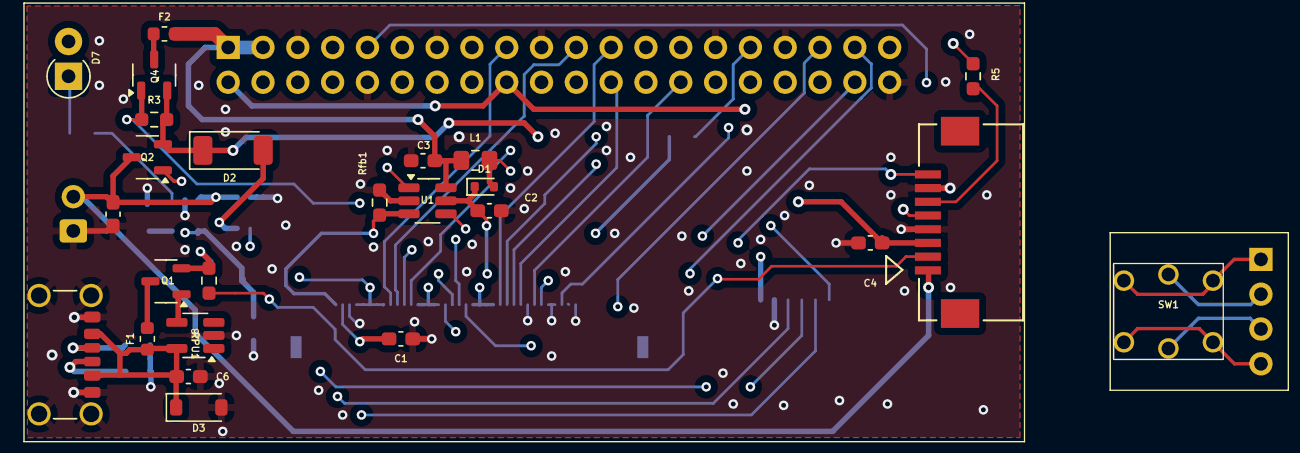
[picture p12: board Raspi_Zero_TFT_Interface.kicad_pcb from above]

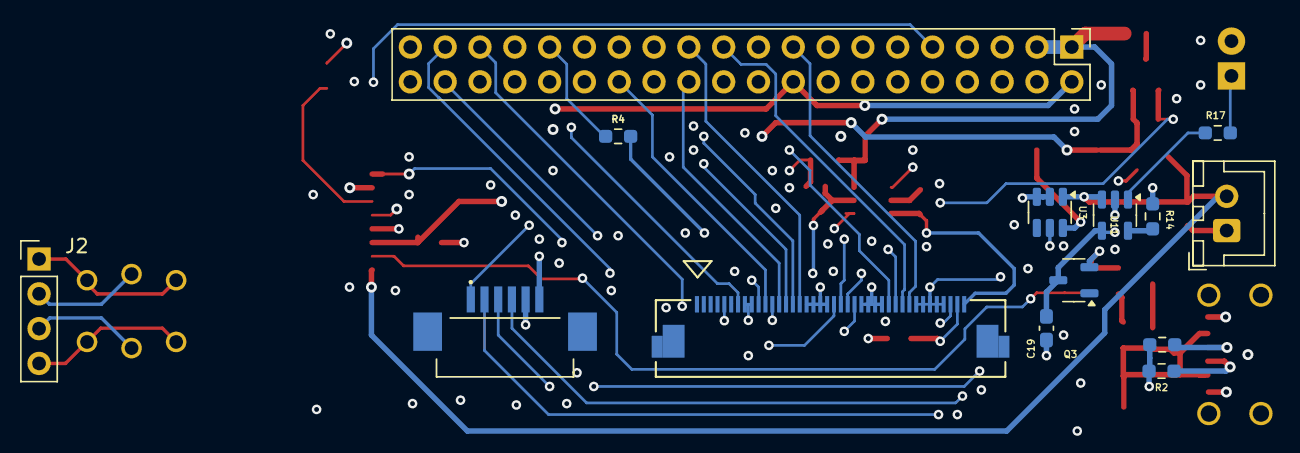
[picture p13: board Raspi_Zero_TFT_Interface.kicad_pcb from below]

Board: 4 copper layers, 39 parts (14 on the bottom side), 50 nets.

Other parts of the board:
C20: 10u; C_0603_1608Metric_Pad1.08x0.95mm_HandSolder

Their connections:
/V_Batt: C20.1; also elsewhere on the board
GND: C20.2; also elsewhere on the board

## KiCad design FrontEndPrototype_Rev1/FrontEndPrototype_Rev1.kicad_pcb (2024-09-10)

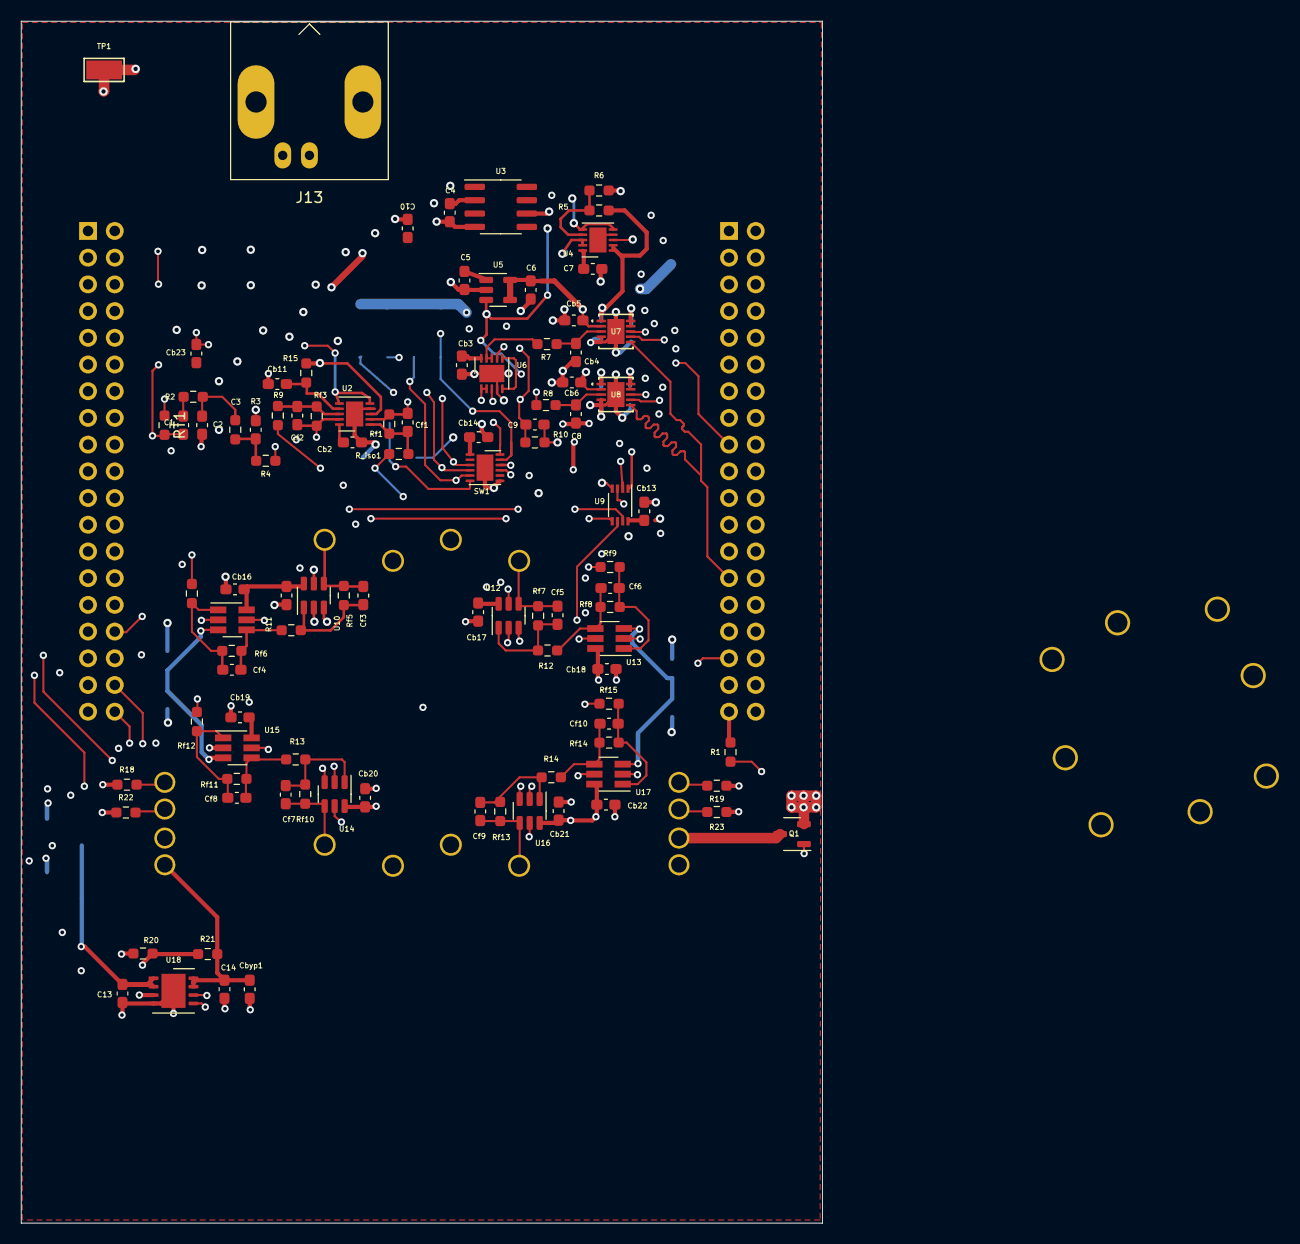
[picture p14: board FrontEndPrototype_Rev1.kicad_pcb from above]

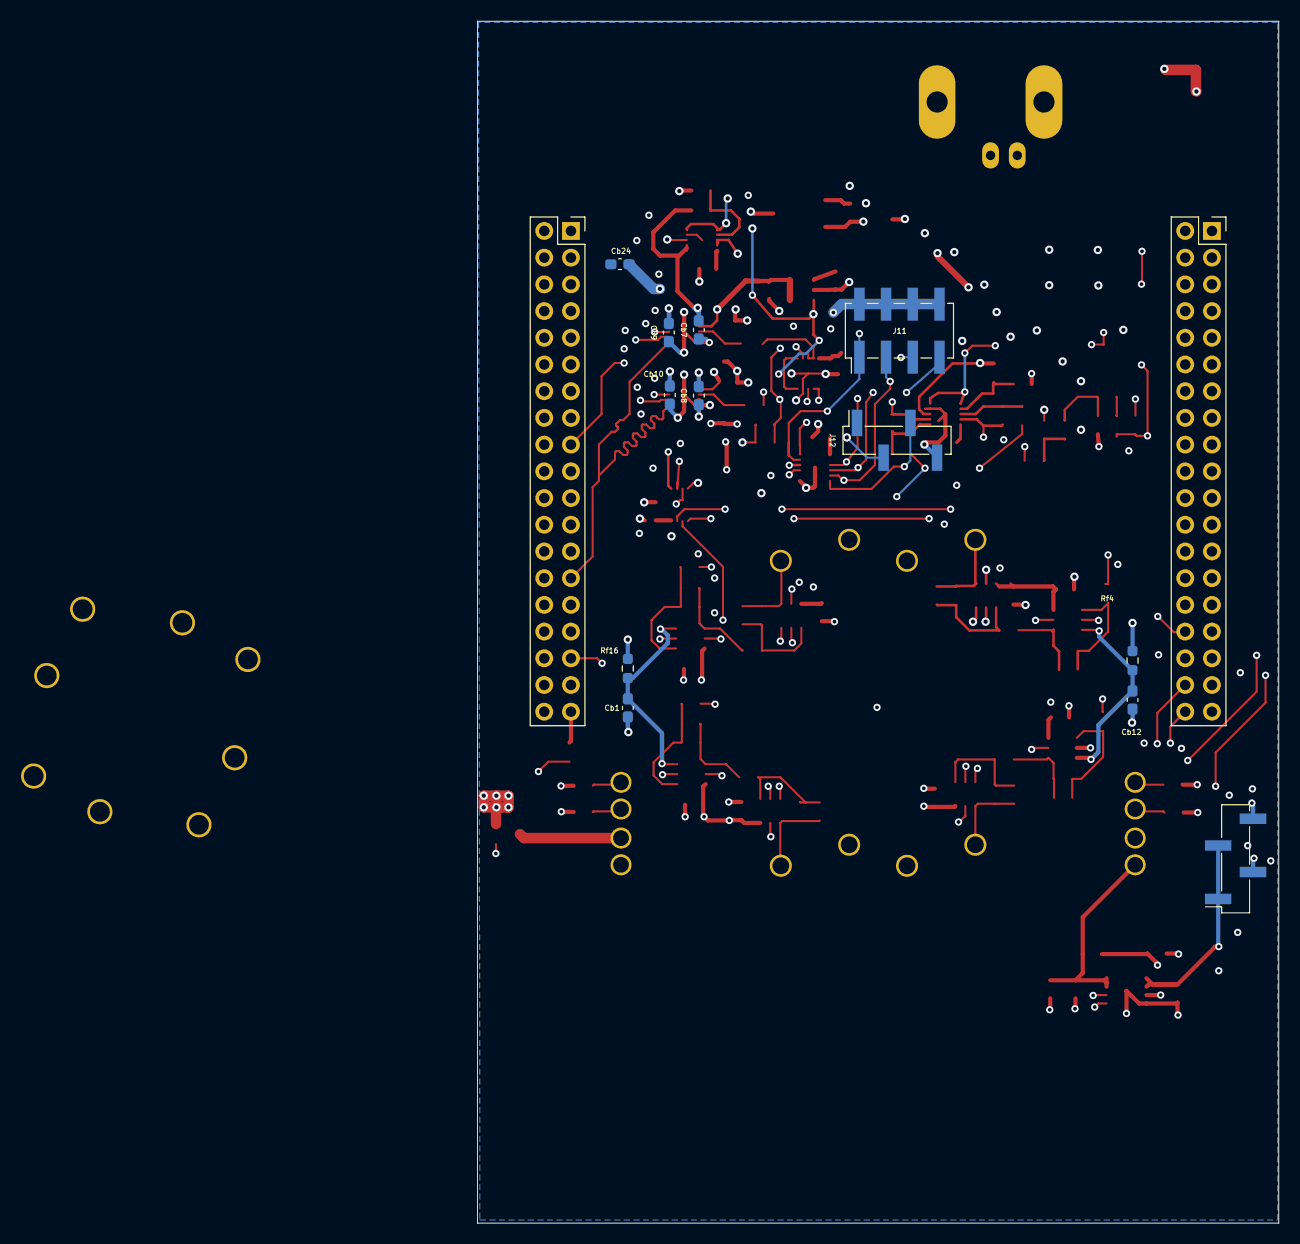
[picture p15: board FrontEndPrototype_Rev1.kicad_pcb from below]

Board: 4 copper layers, 76.2 x 114.3 mm, 124 parts (14 on the bottom side), 72 nets.

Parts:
C1: 100p; C_0603_1608Metric_Pad1.08x0.95mm_HandSolder
C2, C3: 47p; C_0603_1608Metric_Pad1.08x0.95mm_HandSolder
C4, C7: 1uF; C_0603_1608Metric_Pad1.08x0.95mm_HandSolder
C5, C6, C13, C14: 10uF; C_0603_1608Metric_Pad1.08x0.95mm_HandSolder
C8: 220p; C_0603_1608Metric_Pad1.08x0.95mm_HandSolder
C9: 1u; C_0603_1608Metric_Pad1.08x0.95mm_HandSolder
C10: 22uF; C_0603_1608Metric_Pad1.08x0.95mm_HandSolder
Cb1, Cb7, Cb8, Cb12, Cb23: 10u; C_0603_1608Metric_Pad1.08x0.95mm_HandSolder
Cb2, Cb3, Cb5, Cb6, Cb9, Cb10, Cb13, Cb15, Cb16, Cb17, Cb18, Cb19, Cb20, Cb21, Cb22, Cb24: 0.1u; C_0603_1608Metric_Pad1.08x0.95mm_HandSolder
Cb4: 220p; C_0603_1608Metric_Pad1.08x0.95mm_HandSolder
Cb11, Cb14: 1u; C_0603_1608Metric_Pad1.08x0.95mm_HandSolder
Cbyp1: 470nF; C_0603_1608Metric_Pad1.08x0.95mm_HandSolder
Cf1: 27p; C_0603_1608Metric_Pad1.08x0.95mm_HandSolder
Cf2, Cf4, Cf6, Cf8, Cf10: 1p; C_0603_1608Metric_Pad1.08x0.95mm_HandSolder
Cf3, Cf5, Cf7, Cf9: 200p; C_0603_1608Metric_Pad1.08x0.95mm_HandSolder
J1, J2: Conn_02x19_Odd_Even; PinSocket_2x19_P2.54mm_Vertical
J3, J4, J5, J6, J7, J8, J9, J10: MIllMaxSpringConnector; MillMax_0914-2
J11: Conn_02x04_Odd_Even; PinHeader_2x04_P2.54mm_Vertical_SMD
J12, J15: Conn_02x02_Odd_Even; PinHeader_1x04_P2.54mm_Vertical_SMD_Pin1Right
J13: Conn_Coaxial; BNC_TE_Connectivity_RightAngle_THT
J19, J20, J21, J22: Conn_01x02_Pin; Samtec_Pin_Socket_SS_102_G_2
Q1: PMV30UN2; SOT-23-3
R1, R2, R3, R5, R6: 10k; R_0603_1608Metric_Pad0.98x0.95mm_HandSolder
R4: 2k; R_0603_1608Metric_Pad0.98x0.95mm_HandSolder
R7, R8, R10: 100; R_0603_1608Metric_Pad0.98x0.95mm_HandSolder
R9, R11, R12, R13, R14, R15, R18, R19, R20, R22, R23: 1k; R_0603_1608Metric_Pad0.98x0.95mm_HandSolder
R21: 5.6k; R_0603_1608Metric_Pad0.98x0.95mm_HandSolder
RT1: 50; R_0603_1608Metric_Pad0.98x0.95mm_HandSolder
R_iso1: 10; R_0603_1608Metric_Pad0.98x0.95mm_HandSolder
Rf1: 2.5k; R_0603_1608Metric_Pad0.98x0.95mm_HandSolder
Rf3, Rf6, Rf8, Rf11, Rf14: 50k; R_0603_1608Metric_Pad0.98x0.95mm_HandSolder
Rf4, Rf16: 100; R_0603_1608Metric_Pad0.98x0.95mm_HandSolder
Rf5, Rf7, Rf10, Rf13: 50; R_0603_1608Metric_Pad0.98x0.95mm_HandSolder
Rf9, Rf12, Rf15: 10; R_0603_1608Metric_Pad0.98x0.95mm_HandSolder
Riso1: 10; R_0603_1608Metric_Pad0.98x0.95mm_HandSolder
SW1: MAX4704; DFN-12-1EP_3x3mm_P0.5mm_EP1.6x2.5mm
TP1: TestPoint; TestPoint_Keystone_5015_Micro-Minature
U2, U4, U6: ADA4807-2ACP; LFCSP-WD-10-1EP_3x3mm_P0.5mm_EP1.64x2.38mm
U3: ADR4530; SOIC-8_3.9x4.9mm_P1.27mm
U5: ADP7118-1.8; TSOT-23-5
U7, U8: AD4002_LFSCP-10; CP_10_9_ADI
U9: 74LVC1G139; VSSOP-8_2.3x2mm_P0.5mm
U10, U12, U14, U16: LTC6252; TSOT-23-6
U11, U13, U15, U17: ADA4807-1; SOT-23-6_Handsoldering
U18: LD39200; DFN-8-1EP_4x4mm_P0.8mm_EP2.3x3.24mm

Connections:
5V: J1.18, J15.4
/ABBCore_Alt/TIA_1/V_MID: Cb12.2, Rf4.2, U10.3 (+), U11.3 (+), U14.3 (+), U15.3 (+)
/ABBCore_Alt/TIA_1/V_OUT: J11.1, Riso1.2, SW1.11 (NO0)
/ABBCore_Alt/TIA_2/V_MID: Cb1.2, Rf16.2, U12.3 (+), U13.3 (+), U16.3 (+), U17.3 (+)
/ABBCore_Alt/TIA_2/V_OUT: J11.3, Rf9.2, SW1.5 (NO1)
/ABBCore_Alt/TIA_3/V_OUT: J11.5, Rf12.2, SW1.3 (NO2)
/ABBCore_Alt/TIA_4/V_OUT: J11.7, Rf15.2, SW1.4 (NO3)
/ABBCore_Alt/V_Drive: J3.1, J5.1, J7.1, J8.1, R9.2, R_iso1.2
/ABBCore_Alt/V_Exc: Cf2.2, Rf3.2, U2.9, U6.7 (+)
/ABBCore_Alt/V_Resp: C9.2, J11.2, J11.4, J11.6, J11.8, R10.2, SW1.12 (COM), U6.3 (+)
/ABBCore_Alt/~TIA1_SHDN: U9.7 (Y0), U10.5 (~SHDN), U11.5 (~DISABLE)
/ABBCore_Alt/~TIA2_SHDN: U9.6 (Y1), U12.5 (~SHDN), U13.5 (~DISABLE)
/ABBCore_Alt/~TIA3_SHDN: U9.5 (Y2), U14.5 (~SHDN), U15.5 (~DISABLE)
/ABBCore_Alt/~TIA4_SHDN: U9.3 (Y3), U16.5 (~SHDN), U17.5 (~DISABLE)
/Heater_Interface/Vdd: C13.1, J15.1, J15.3, U18.1 (Vin), U18.2 (Vin)
ADC_VREF: Cb7.2, Cb8.2, R5.1, U4.1, U4.2 (-), U7.1 (REF), U8.1 (REF)
CCOut_1: Cf3.1, J6.1, Rf5.1, U10.4 (-)
CCOut_2: Cf5.1, J9.1, Rf7.1, U12.4 (-)
CCOut_3: Cf7.1, J4.1, Rf10.1, U14.4 (-)
CCOut_4: Cf9.1, J10.1, Rf13.1, U16.4 (-)
CNV: J2.27, U7.6 (CNV), U8.6 (CNV)
D0: J2.21, SW1.10 (ADDA), U9.1 (A)
D1: J2.23, SW1.9 (ADDB), U9.2 (B)
DataOut1: J2.5, U8.7 (SDO)
Dataout0: J2.3, U7.7 (SDO)
GND: C2.2, C3.2, C4.2, C5.2, C6.2, C7.2, C8.1, C9.1, C10.1, C13.2, C14.1, Cb1.1, Cb2.1, Cb3.2, Cb4.1, Cb5.2, Cb6.2, Cb7.1, Cb8.1, Cb9.1, Cb10.1, Cb11.1, Cb12.1, Cb13.1, Cb14.1, Cb15.1, Cb16.1, Cb17.1, Cb18.1, Cb19.1, Cb20.1, Cb21.1, Cb22.1, Cb23.1, Cb24.1, Cbyp1.1, J1.8, J1.19, J1.20, J2.9, J2.20, J2.32, J12.4, J13.2 (Ext), J19.2, J21.2, Q1.2 (S), R6.2, R10.1, R18.1, R19.1, R20.1, R22.1, R23.1, RT1.1, SW1.7 (GND), TP1.1, U2.4 (V-), U2.11 (EPAD), U3.4 (GND), U4.4 (V-), U4.11 (EPAD), U5.2 (GND), U6.4 (V-), U6.11 (EPAD), U7.4 (IN-), U7.5 (GND), U7.11 (Pad), U8.4 (IN-), U8.5 (GND), U8.11 (Pad), U9.4 (GND), U10.2 (V-), U11.2 (V-), U12.2 (V-), U13.2 (V-), U14.2 (V-), U15.2 (V-), U16.2 (V-), U17.2 (V-), U18.4 (GND), U18.9 (GND)
Heater_EN: J1.25, U18.6 (EN)
Heater_PG: J1.27, U18.5 (PWRGD)
Heater_PWM: J2.37, R1.2
Heating_Element: J21.1, Q1.3 (D)
MCU_SCK: J2.17, U7.8 (SCK), U8.8 (SCK)
unnamed: C1.1, R2.1
unnamed: C2.1, R2.2, R3.1
unnamed: C3.1, R3.2, R4.1
unnamed: Cf1.1, R_iso1.1, Rf1.1, U2.1
unnamed: Cf3.2, R11.2, Rf5.2, U10.1
unnamed: Cf4.2, Rf6.2, Riso1.1, U11.1
unnamed: Cf5.2, R12.2, Rf7.2, U12.1
unnamed: Cf6.2, Rf8.2, Rf9.1, U13.1
unnamed: Cf7.2, R13.2, Rf10.2, U14.1
unnamed: Cf8.2, Rf11.2, Rf12.1, U15.1
unnamed: Cf9.2, R14.2, Rf13.2, U16.1
unnamed: Cf10.2, Rf14.2, Rf15.1, U17.1
unnamed: J12.3, SW1.6 (INH)
unnamed: Q1.1 (G), R1.1
unnamed: Cf1.2, R4.2, Rf1.2, U2.2 (-)
unnamed: Cb11.2, R15.2, U2.7 (+)
unnamed: Cf2.1, R9.1, Rf3.1, U2.8 (-)
unnamed: U3.6 (OUT), U4.3 (+)
unnamed: R5.2, R6.1, U4.7 (+)
unnamed: R8.2, U6.1, U6.2 (-)
unnamed: R7.2, U6.8 (-), U6.9
unnamed: Cb4.2, R7.1, U7.3 (IN+)
unnamed: C8.2, R8.1, U8.3 (IN+)
unnamed: Cf4.1, R11.1, Rf6.1, U11.4 (-)
unnamed: Cf6.1, R12.1, Rf8.1, U13.4 (-)
unnamed: Cf8.1, R13.1, Rf11.1, U15.4 (-)
unnamed: Cf10.1, R14.1, Rf14.1, U17.4 (-)
unnamed: R20.2, R21.1, U18.3 (ADJ/SENSE)
V_BAT: J1.33, J15.2
V_MID: R15.1, Rf4.1, Rf16.1, U2.3 (+), U4.8 (-), U4.9
V_SIG: C1.2, J1.32, J13.1 (In), RT1.2
Vdd_ADC: C6.1, Cb5.1, Cb6.1, U5.4 (SENSE/ADJ), U5.5 (VOUT), U7.2 (Vdd), U8.2 (Vdd)
Vdd_Heater: C14.2, Cbyp1.2, J19.1, R21.2, U18.7 (Vout), U18.8 (Vout)
Vdd_MCU: Cb9.2, Cb10.2, Cb24.2, J1.5, U7.9 (SDI), U7.10 (VIO), U8.9 (SDI), U8.10 (VIO)
Vdd_Main: C4.1, C5.1, C7.1, C10.2, Cb2.2, Cb3.1, Cb13.2, Cb14.2, Cb15.2, Cb16.2, Cb17.2, Cb18.2, Cb19.2, Cb20.2, Cb21.2, Cb22.2, Cb23.2, J1.12, J12.2, SW1.1 (V+), U2.10 (V+), U3.2 (IN), U4.10 (V+), U5.1 (VIN), U6.10 (V+), U9.8 (VCC), U10.6 (V+), U11.6 (V+), U12.6 (V+), U13.6 (V+), U14.6 (V+), U15.6 (V+), U16.6 (V+), U17.6 (V+)
Vth_1: J1.36, J20.1, R18.2
Vth_2: J2.33, J22.1, R19.2
Vth_3: J1.38, J20.2, R22.2
Vth_4: J2.29, J22.2, R23.2
~ADC1_SHDN: J2.4, U4.5 (~DISABLE1), U4.6 (~DISABLE2), U5.3 (EN), U6.5 (~DISABLE1), U6.6 (~DISABLE2)
~CC_Drive_SHDN: J1.13, U2.5 (~DISABLE1), U2.6 (~DISABLE2)

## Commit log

2024-09-10 Initial File Commit
    [ABBCore_alt.kicad_sch, ADC_Drivers_4807_pseudo.kicad_sch, CC_Driver.kicad_sch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]
2024-09-10 Heater and Footprint Initial Commit
    [FrontEndPrototype_Rev1_Heater.kicad_pcb, FrontEndPrototype_Rev1_Heater.kicad_sch]
2024-09-10 Checking if Branch Updates Work
    [ABBCore_alt.kicad_sch, ADC_Drivers_4807_pseudo.kicad_sch, CC_Driver.kicad_sch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]
2024-09-13 Small Updates
    [ABBCore_alt.kicad_sch, CC_Driver.kicad_sch, FrontEndPrototype_Rev1.kicad_sch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]
2024-09-16 Finished USB-C Power Board Design
    [FrontEndPrototype_Rev1_4Channel.kicad_pcb, OVP_Circuit.kicad_sch, Power_Management_Board.kicad_sch]
2024-10-02 Raspberry Pi Board Added
    [52271-0679.step, OVP_Circuit.kicad_sch, Power_Management_Board.kicad_sch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]
2024-10-03 First draft layout of power pi board
    [OVP_Circuit.kicad_sch, Pwr_Mgmt_Min.kicad_sch, Raspi_Zero_TFT_Interface.kicad_pcb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]
2024-10-05 Completed (unflipped) board
    [FrontEndPrototype_Rev2_Heater.kicad_pcb, FrontEndPrototype_Rev2_Heater.kicad_sch, Pwr_Mgmt_Min.kicad_sch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]
2024-10-06 Partial Update
    [Raspi_Zero_TFT_Interface.kicad_pcb, Raspi_Zero_TFT_Interface.kicad_sch]
2024-10-07 Finalized Ras_Pi Power Board
    [Raspi_Zero_TFT_Interface.kicad_pcb, Raspi_Zero_TFT_Interface.kicad_sch]
2024-10-07 Small change to Raspi Board
    [ABBCore_alt.kicad_sch, ADC_Drivers_4807_pseudo.kicad_sch, CC_Driver.kicad_sch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]
2024-10-08 Finished Measurement Board Update Minus Heater Board Connections
    [ABBCore_alt.kicad_sch, Heater_Interface.kicad_sch, MCU_Connections_STM32WB55.kicad_sch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]
2024-10-11 Boards nearly finalized
    [FrontEndPrototype_Rev2_Heater.kicad_pcb, FrontEndPrototype_Rev2_Heater.kicad_sch]
2024-10-25 Nearly Finalized Boards
    [Combined_Rev2_Board.kicad_pcb, Combined_Rev2_Board.kicad_sch, FrontEndPrototype_Rev2_Heater.kicad_pcb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]
2024-10-28 Final commit before order
    [ADC_Drivers_4807_pseudo.kicad_sch, CC_Driver.kicad_sch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]
2024-10-28 Following Board Resubmit
    [Combined_Rev2_Board-B_Cu.gbr, Combined_Rev2_Board-B_Mask.gbr, Combined_Rev2_Board-B_Silkscreen.gbr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]
2025-01-30 Final Rev 2 Commit
    [MeasurementBoard_Rev2.kicad_pcb, Raspi_Zero_TFT_Interface.kicad_pcb]
2025-01-30 Added Readme
    [Raspi_Zero_TFT_Interface.kicad_sch]
2025-01-31 First Pass Schematic Fixes for Power Management Board
    [ABBCore_alt.kicad_sch, ADC_Drivers_4807_pseudo.kicad_sch, CC_Driver.kicad_sch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]
2025-02-03 Finished Rasp Board PCB Routing
    [OVP_Circuit.kicad_sch, Pwr_Mgmt_Min.kicad_sch, Raspi_Zero_TFT_Interface.kicad_pcb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]
2025-02-03 Finished Measurement Board Fixes Schematic and PCB
    [Heater_Interface.kicad_sch, MCU_Connections_STM32WB55.kicad_sch, MeasurementBoard_Rev2.kicad_pcb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]
2025-02-04 Updated Measurement Board with new 3V Reference
    [ABBCore_alt.kicad_sch, ADC_Drivers_4807_pseudo.kicad_sch, CC_Driver.kicad_sch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]
2025-02-05 Final Edit Before Check and Combine
    [FrontEndPrototype_Rev2_Heater.kicad_pcb, FrontEndPrototype_Rev2_Heater.kicad_sch, MeasurementBoard_Rev2.kicad_pcb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]
2025-02-10 Final Rev3 Commit Post Submission
    [CalibrationBoards_4Channel.kicad_pcb, CalibrationBoards_4Channel.kicad_sch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]
